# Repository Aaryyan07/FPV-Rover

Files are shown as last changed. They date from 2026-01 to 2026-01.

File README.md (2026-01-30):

# Arduino Mega Rover (Dual-Arm & FPV)

This is a custom-built rover project I designed using an Arduino Mega. It features a differential drive base, a robotic arm with 5 degrees of freedom, and a full FPV telemetry system.

The project is split into two main control systems: one for driving the wheels and one for operating the arm, both controlled simultaneously via two separate FlySky transmitters.

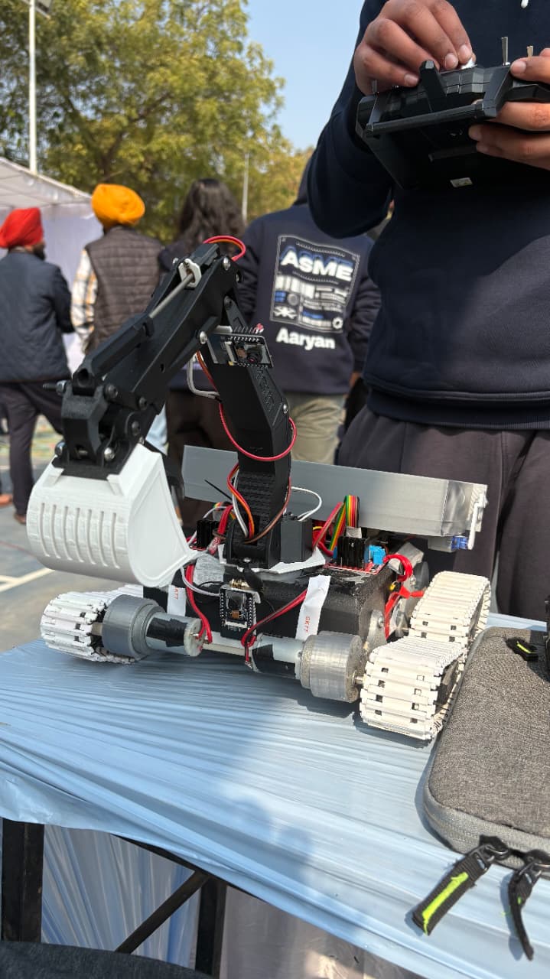
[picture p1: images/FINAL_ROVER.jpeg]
Final Rover Model


## Hardware Setup

### The Base (Drive System)
* **Motors:** 4x Johnson Geared Motors (12V DC, 500 RPM, Grade B).
* **Drivers:** 2x L298N Motor Drivers (controlling the 4 wheels).
* **Power:** Powered directly from the 12V rail of a PDB-XT60.

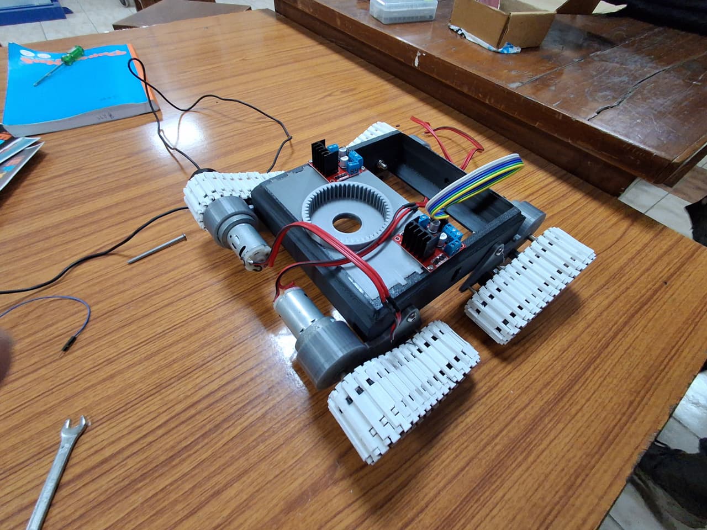
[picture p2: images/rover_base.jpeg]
Rover Base


### The Arm (Manipulation)
* **Actuators:** 5x N20 Motors with 100mm threaded shafts (Linear Actuators, 12V 1000 RPM).
* **Lift:** 1x N20 Motor.
* **Gripper:** Servo motor (PWM controlled via Arduino).
* **Drivers:** 3x TB6612FNG Dual Motor Drivers.
    * *Note: I used TB6612FNGs here instead of L298Ns to save space and reduce heat for the smaller arm motors.*
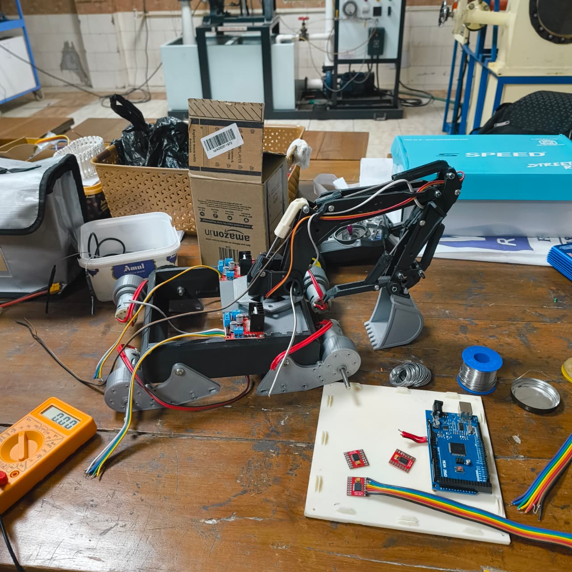
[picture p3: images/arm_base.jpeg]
Arm base


### Electronics & FPV
* **Microcontroller:** Arduino Mega (Handles all PWM logic and motor mixing).
* **RC Control:** 2x FS-IA10B Receivers paired with FlySky Transmitters.
* **Camera:** Foxeer Predator 5 connected to a Zeus HGLRC Nano VTX.
* **Video Receiver:** Skydroid 5.8GHz receiver with Lollipop antennas (RHCP) on both ends for better signal clarity.
* **Power:** 3S LiPo Battery (12.6V) connected to a PDB-XT60.

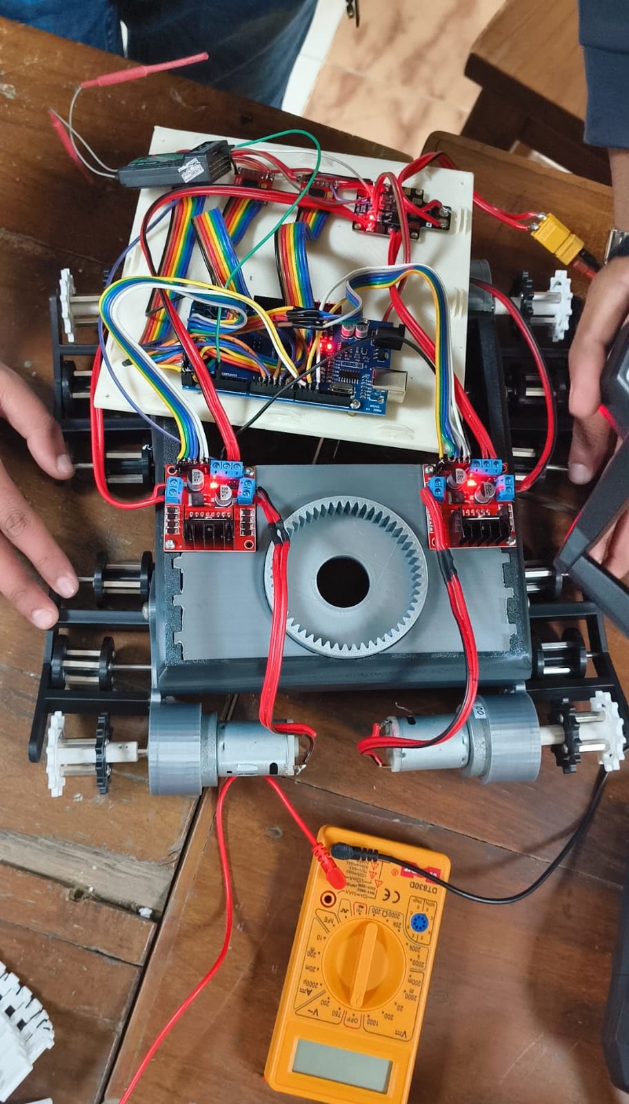
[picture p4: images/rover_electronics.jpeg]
Rover Electronics


## Wiring & Noise Reduction
One of the main challenges with this build was electrical noise from the DC motors interfering with the receiver signals.
* **Power Distribution:** The PDB-XT60 splits power: 12V to the drivers and 5V to the camera/transmitters.
* **Filtering:** I added capacitors across the motor driver terminals to smooth out voltage spikes and ensure the Arduino and receivers get a clean signal.

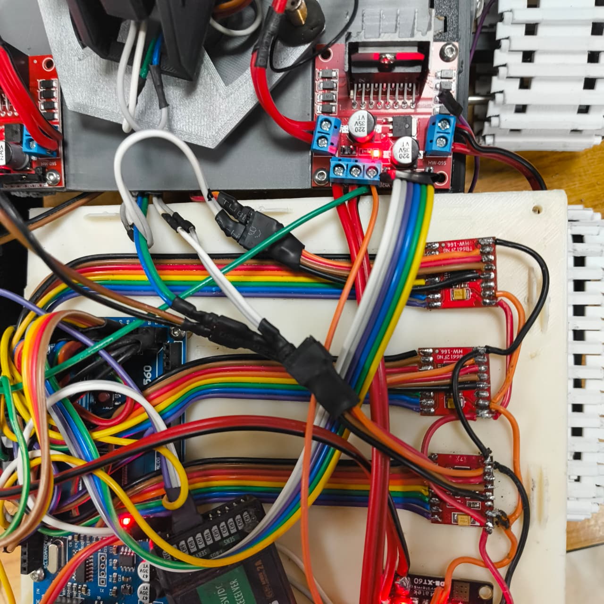
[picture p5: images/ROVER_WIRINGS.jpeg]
Wirings


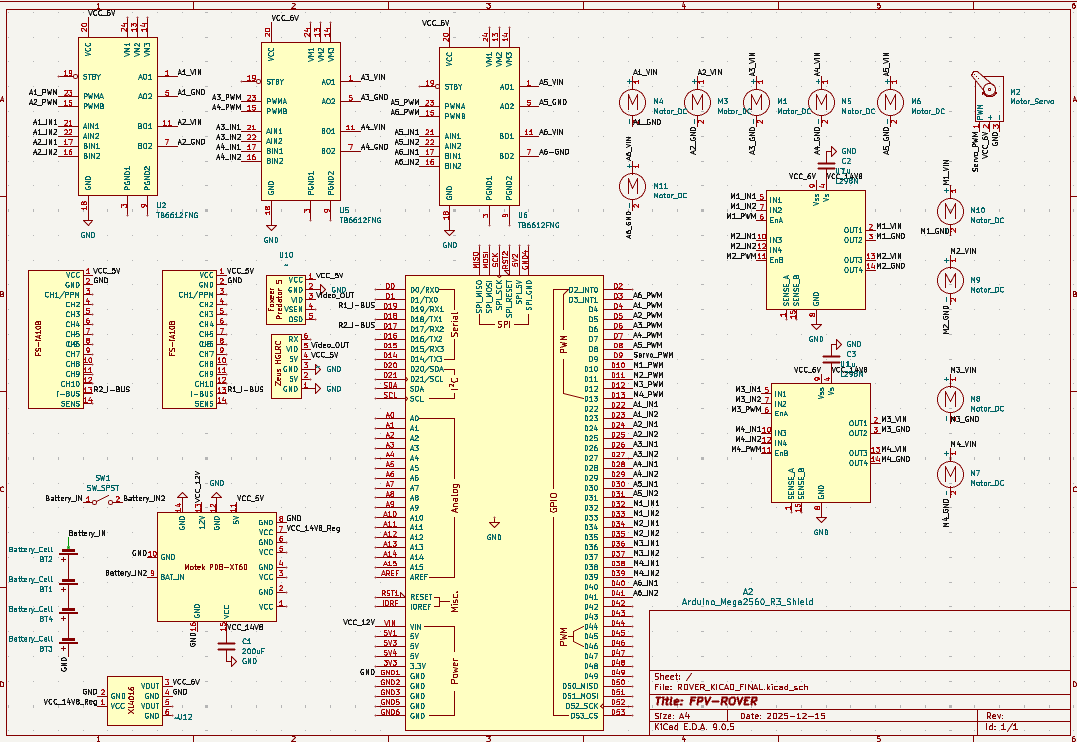
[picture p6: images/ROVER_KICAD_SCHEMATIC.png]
Schematic

## Fabrication
All mechanical parts (chassis, arm linkages, mounts) were 3D printed using **ABS filament** in the university mechanical lab. ABS was chosen over PLA for its higher heat resistance and durability.

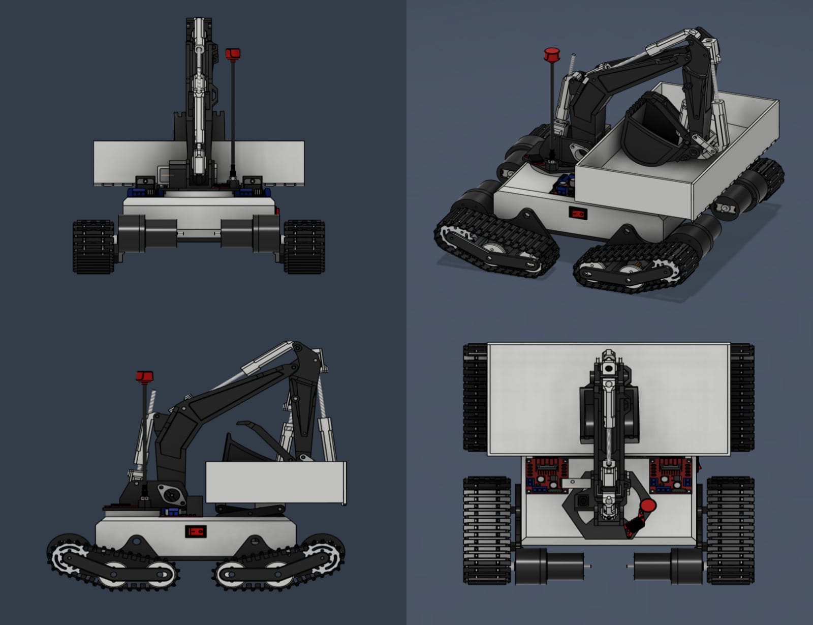
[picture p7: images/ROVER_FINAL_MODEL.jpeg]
Model


---
*Project by Aaryan Rathore*

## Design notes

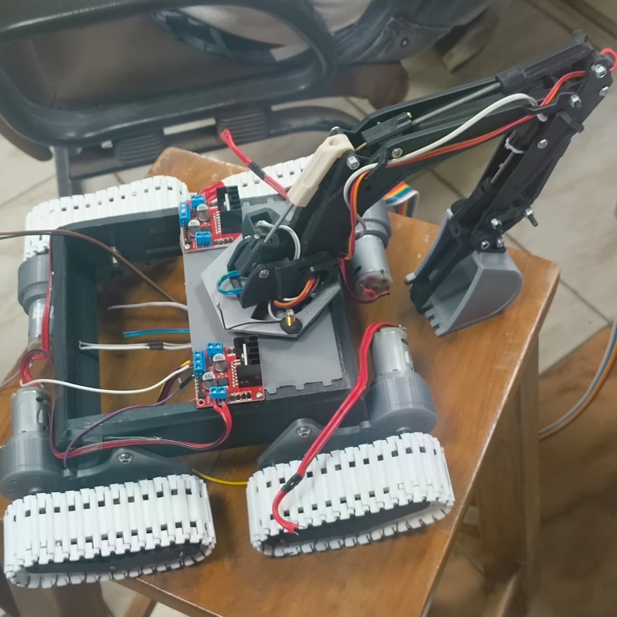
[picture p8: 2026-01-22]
images/rover_arm_base.jpeg

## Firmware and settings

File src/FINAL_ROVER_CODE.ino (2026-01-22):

#include <IBusBM.h>
#include <Servo.h>

const int MAX_SPEED_ROVER      = 255; 

const int MAX_SPEED_ARM_BASE   = 200;  
const int MAX_SPEED_ARM_LOWER  = 255;  
const int MAX_SPEED_ARM_UPPER  = 255;  
const int MAX_SPEED_ARM_DIGGER = 255;  
const int MAX_SPEED_ARM_CLIPPER= 200;  
const int MAX_SPEED_ARM_LIFT   = 255;  

const int SERVO_MIN_ANGLE      = 0;
const int SERVO_MAX_ANGLE      = 180;

const int LEFT_ENA = 2;   const int LEFT_IN1 = 49; const int LEFT_IN2 = 47; 
const int LEFT_IN3 = 45;  const int LEFT_IN4 = 43; const int LEFT_ENB = 3;

const int RIGHT_ENA = 10; const int RIGHT_IN1 = 37; const int RIGHT_IN2 = 35; 
const int RIGHT_IN3 = 33; const int RIGHT_IN4 = 31; const int RIGHT_ENB = 11;

const int SERVO_PIN = 9; 

const int D1_PWMA = 12;   const int D1_AIN1 = 46; const int D1_AIN2 = 44; 
const int D1_PWMB = 13;   const int D1_BIN1 = 48; const int D1_BIN2 = 50; 

const int D2_PWMA = 4;   const int D2_AIN1 = 28; const int D2_AIN2 = 26; 
const int D2_PWMB = 5;   const int D2_BIN1 = 30; const int D2_BIN2 = 32; 

const int D3_PWMA = 7;   const int D3_AIN1 = 38; const int D3_AIN2 = 36; 
const int D3_PWMB = 6;   const int D3_BIN1 = 40; const int D3_BIN2 = 42; 

const int STDBY1 = 22;
const int STDBY2 = 23;

const int CH_ROVER_ROLL = 0;    
const int CH_ROVER_PITCH = 1;   
const int CH_ROVER_SERVO = 4;   
const int CH_ROVER_LIFT = 3;    
const int CH_ROVER_EMERGENCY = 9;   

const int CH_ARM_LOWER = 0;     
const int CH_ARM_UPPER = 1;     
const int CH_ARM_SAFETY = 2;    
const int CH_ARM_BASE = 3;      
const int CH_ARM_DIGGER = 4;    
const int CH_ARM_CLIPPER = 5;   

const int CH_ARM_CALIBRATE = 7;    
const int CH_ARM_RESET_POS = 6;    

IBusBM IBusRover; 
IBusBM IBusArm;   
Servo myServo;    

int globalLeftSpeed = 0;
int globalRightSpeed = 0;

const int CALIBRATION_SPEED = 200; 

unsigned long lastDebugTime = 0;

unsigned long previousTime = 0;
float deltaTime = 0.0;

float posLeftA = 0.0, posLeftB = 0.0;
float posRightA = 0.0, posRightB = 0.0;
float posBase = 0.0, posDigger = 0.0, posClipper = 0.0;
float posLowerArm = 0.0, posUpperArm = 0.0, posLift = 0.0;

const float SPEED_TO_DIST = 0.5; 

const float CALIBRATION_TOLERANCE = 5.0;
const int SIGNAL_TIMEOUT = 1000; 
unsigned long lastValidSignalTime = 0;

void displayFullSystemDebug();
int mapSpeed(int rcVal, int maxLimit);

void setup() {
  Serial.begin(115200);
  previousTime = millis();
  
  pinMode(LEFT_ENA, OUTPUT);  pinMode(LEFT_IN1, OUTPUT);  pinMode(LEFT_IN2, OUTPUT);
  pinMode(LEFT_IN3, OUTPUT);  pinMode(LEFT_IN4, OUTPUT);  pinMode(LEFT_ENB, OUTPUT);
  pinMode(RIGHT_ENA, OUTPUT); pinMode(RIGHT_IN1, OUTPUT); pinMode(RIGHT_IN2, OUTPUT);
  pinMode(RIGHT_IN3, OUTPUT); pinMode(RIGHT_IN4, OUTPUT); pinMode(RIGHT_ENB, OUTPUT);

  pinMode(D1_PWMA, OUTPUT); pinMode(D1_AIN1, OUTPUT); pinMode(D1_AIN2, OUTPUT);
  pinMode(D1_PWMB, OUTPUT); pinMode(D1_BIN1, OUTPUT); pinMode(D1_BIN2, OUTPUT);
  pinMode(D2_PWMA, OUTPUT); pinMode(D2_AIN1, OUTPUT); pinMode(D2_AIN2, OUTPUT);
  pinMode(D2_PWMB, OUTPUT); pinMode(D2_BIN1, OUTPUT); pinMode(D2_BIN2, OUTPUT);
  pinMode(D3_PWMA, OUTPUT); pinMode(D3_AIN1, OUTPUT); pinMode(D3_AIN2, OUTPUT);
  pinMode(D3_PWMB, OUTPUT); pinMode(D3_BIN1, OUTPUT); pinMode(D3_BIN2, OUTPUT);

  pinMode(STDBY1, OUTPUT); digitalWrite(STDBY1, HIGH);
  pinMode(STDBY2, OUTPUT); digitalWrite(STDBY2, HIGH);

  myServo.attach(SERVO_PIN);
  
  IBusRover.begin(Serial1); 
  IBusArm.begin(Serial2);   

  Serial.println("SYSTEM READY. FULL DEBUG MODE + SPEED LIMITS ACTIVE.");
  lastValidSignalTime = millis();
}

void loop() {
  
  unsigned long currentTime = millis();
  deltaTime = (currentTime - previousTime) / 1000.0; 
  previousTime = currentTime;
  
  int emergencySignal = IBusRover.readChannel(CH_ROVER_EMERGENCY);
  int calibrateSignal = IBusArm.readChannel(CH_ARM_CALIBRATE);
  int resetPosSignal = IBusArm.readChannel(CH_ARM_RESET_POS);
  
  bool roverSignalValid = (IBusRover.readChannel(CH_ROVER_ROLL) >= 900 && IBusRover.readChannel(CH_ROVER_ROLL) <= 2100);
  bool armSignalValid = (IBusArm.readChannel(CH_ARM_LOWER) >= 900 && IBusArm.readChannel(CH_ARM_LOWER) <= 2100);
  
  if (roverSignalValid || armSignalValid) {
    lastValidSignalTime = millis();
  }
  
  if (emergencySignal > 1900 || (millis() - lastValidSignalTime > SIGNAL_TIMEOUT)) {
    setL298N(LEFT_ENA, LEFT_IN1, LEFT_IN2, 0);
    setL298N(LEFT_ENB, LEFT_IN3, LEFT_IN4, 0);
    setL298N(RIGHT_ENA, RIGHT_IN1, RIGHT_IN2, 0);
    setL298N(RIGHT_ENB, RIGHT_IN3, RIGHT_IN4, 0);
    
    moveArmMotor(D3_PWMA, D3_AIN1, D3_AIN2, 0);
    moveArmMotor(D1_PWMA, D1_AIN1, D1_AIN2, 0);
    moveArmMotor(D1_PWMB, D1_BIN1, D1_BIN2, 0);
    moveArmMotor(D2_PWMA, D2_AIN1, D2_AIN2, 0);
    moveArmMotor(D2_PWMB, D2_BIN1, D2_BIN2, 0);
    moveArmMotor(D3_PWMB, D3_BIN1, D3_BIN2, 0);
    
    if (millis() - lastDebugTime > 500) {
      if (emergencySignal > 1900) Serial.println("!!! EMERGENCY STOP ACTIVATED !!!");
      else Serial.println("!!! SIGNAL LOST - MOTORS STOPPED !!!");
      lastDebugTime = millis();
    }
    return; 
  }
  
  if (resetPosSignal > 1900) {
    posLeftA = 0.0; posLeftB = 0.0; posRightA = 0.0; posRightB = 0.0;
    posBase = 0.0; posDigger = 0.0; posClipper = 0.0;
    posLowerArm = 0.0; posUpperArm = 0.0; posLift = 0.0;
    
    if (millis() - lastDebugTime > 1000) {
       Serial.println("--- POSITIONS RESET TO 0.0 ---");
       lastDebugTime = millis();
    }
    return;
  }
  
  if (calibrateSignal > 1900) {
    myServo.write(SERVO_MIN_ANGLE); 
    setL298N(LEFT_ENA, LEFT_IN1, LEFT_IN2, 0);
    setL298N(LEFT_ENB, LEFT_IN3, LEFT_IN4, 0);
    setL298N(RIGHT_ENA, RIGHT_IN1, RIGHT_IN2, 0);
    setL298N(RIGHT_ENB, RIGHT_IN3, RIGHT_IN4, 0);

    int speedBase = calculateCalibrationSpeed(posBase);
    int speedDigger = calculateCalibrationSpeed(posDigger);
    int speedClipper = calculateCalibrationSpeed(posClipper);
    int speedLowerArm = calculateCalibrationSpeed(posLowerArm);
    int speedUpperArm = calculateCalibrationSpeed(posUpperArm);
    int speedLift = calculateCalibrationSpeed(posLift);

    moveArmMotor(D3_PWMA, D3_AIN1, D3_AIN2, speedBase);
    moveArmMotor(D1_PWMA, D1_AIN1, D1_AIN2, speedDigger);
    moveArmMotor(D1_PWMB, D1_BIN1, D1_BIN2, speedClipper);
    moveArmMotor(D2_PWMA, D2_AIN1, D2_AIN2, speedLowerArm);
    moveArmMotor(D2_PWMB, D2_BIN1, D2_BIN2, speedUpperArm);
    moveArmMotor(D3_PWMB, D3_BIN1, D3_BIN2, speedLift);

    updatePositions(0, 0, 0, 0, speedBase, speedDigger, speedClipper, speedLowerArm, speedUpperArm, speedLift);
    
    if (millis() - lastDebugTime > 250) { 
       displayFullSystemDebug();
       lastDebugTime = millis();
    }
    return;
  }

  int rawSafety = IBusArm.readChannel(CH_ARM_SAFETY); 
  int rawBase   = IBusArm.readChannel(CH_ARM_BASE);   
  
  int validBaseVal = 1500;
  if (rawSafety < 1100 && rawSafety > 800) { 
      validBaseVal = rawBase;
  }

  int rawLower   = IBusArm.readChannel(CH_ARM_LOWER);   
  int rawUpper   = IBusArm.readChannel(CH_ARM_UPPER);   
  int rawDigger  = IBusArm.readChannel(CH_ARM_DIGGER);  
  int rawClipper = IBusArm.readChannel(CH_ARM_CLIPPER); 

  int rawRoll   = IBusRover.readChannel(CH_ROVER_ROLL); 
  int rawPitch  = IBusRover.readChannel(CH_ROVER_PITCH);
  int rawServo  = IBusRover.readChannel(CH_ROVER_SERVO);
  int rawLift   = IBusRover.readChannel(CH_ROVER_LIFT); 

  if (millis() - lastDebugTime > 250) { 
    displayFullSystemDebug();
    lastDebugTime = millis();
  }

  if (rawServo >= 1000) {
      int sAngle = map(rawServo, 1000, 2000, SERVO_MIN_ANGLE, SERVO_MAX_ANGLE);
      myServo.write(sAngle);
  }
  
  int throttle = mapPulse(rawPitch);
  int steering = mapPulse(rawRoll);
  
  int leftMotorSpeed = throttle + steering;
  int rightMotorSpeed = throttle - steering;

  globalLeftSpeed = constrain(leftMotorSpeed, -MAX_SPEED_ROVER, MAX_SPEED_ROVER);
  globalRightSpeed = constrain(rightMotorSpeed, -MAX_SPEED_ROVER, MAX_SPEED_ROVER);

  setL298N(LEFT_ENA, LEFT_IN1, LEFT_IN2, globalLeftSpeed);
  setL298N(LEFT_ENB, LEFT_IN3, LEFT_IN4, globalLeftSpeed);
  setL298N(RIGHT_ENA, RIGHT_IN1, RIGHT_IN2, globalRightSpeed);
  setL298N(RIGHT_ENB, RIGHT_IN3, RIGHT_IN4, globalRightSpeed);

  int speedBase     = mapSpeed(validBaseVal, MAX_SPEED_ARM_BASE);
  int speedDigger   = mapSpeed(rawDigger, MAX_SPEED_ARM_DIGGER);
  int speedClipper  = mapSpeed(rawClipper, MAX_SPEED_ARM_CLIPPER);
  int speedLower    = mapSpeed(rawLower, MAX_SPEED_ARM_LOWER);
  int speedUpper    = mapSpeed(rawUpper, MAX_SPEED_ARM_UPPER);
  int speedLift     = mapSpeed(rawLift, MAX_SPEED_ARM_LIFT);

  moveArmMotor(D3_PWMA, D3_AIN1, D3_AIN2, speedBase); 
  moveArmMotor(D1_PWMA, D1_AIN1, D1_AIN2, speedDigger);    
  moveArmMotor(D1_PWMB, D1_BIN1, D1_BIN2, speedClipper);   
  moveArmMotor(D2_PWMA, D2_AIN1, D2_AIN2, speedLower);     
  moveArmMotor(D2_PWMB, D2_BIN1, D2_BIN2, speedUpper);     
  moveArmMotor(D3_PWMB, D3_BIN1, D3_BIN2, speedLift);      

  updatePositions(globalLeftSpeed, globalLeftSpeed, globalRightSpeed, globalRightSpeed,
                  speedBase, speedDigger, speedClipper, speedLower, speedUpper, speedLift);

  delay(10); 
}

void moveArmMotor(int pwm, int in1, int in2, int speed) {
  if (abs(speed) < 10) {
    digitalWrite(in1, LOW); digitalWrite(in2, LOW); analogWrite(pwm, 0);
  } else if (speed > 0) {
    digitalWrite(in1, HIGH); digitalWrite(in2, LOW); analogWrite(pwm, speed);
  } else {
    digitalWrite(in1, LOW); digitalWrite(in2, HIGH); analogWrite(pwm, abs(speed));
  }
}

int mapSpeed(int rcVal, int maxLimit) {
  if (rcVal < 800 || rcVal > 2200) return 0;
  
  int speed = map(rcVal, 1000, 2000, -maxLimit, maxLimit);
  
  if (abs(speed) < 35) speed = 0; 
  return speed;
}

int mapPulse(int val) {
  if (val < 900 || val > 2100) return 0;
  int out = map(val, 1000, 2000, -255, 255);
  return (abs(out) < 25) ? 0 : out;
}

void setL298N(int en, int in1, int in2, int speed) {
  if (abs(speed) < 20) {
    digitalWrite(in1, LOW); digitalWrite(in2, LOW); analogWrite(en, 0);
  } else if (speed > 0) {
    digitalWrite(in1, HIGH); digitalWrite(in2, LOW); analogWrite(en, speed);
  } else {
    digitalWrite(in1, LOW); digitalWrite(in2, HIGH); analogWrite(en, abs(speed));
  }
}

void updatePositions(int sLA, int sLB, int sRA, int sRB,
                     int sBase, int sDig, int sClip, int sLow, int sUp, int sLift) {
  posLeftA += sLA * deltaTime * SPEED_TO_DIST;
  posLeftB += sLB * deltaTime * SPEED_TO_DIST;
  posRightA += sRA * deltaTime * SPEED_TO_DIST;
  posRightB += sRB * deltaTime * SPEED_TO_DIST;
  posBase += sBase * deltaTime * SPEED_TO_DIST;
  posDigger += sDig * deltaTime * SPEED_TO_DIST;
  posClipper += sClip * deltaTime * SPEED_TO_DIST;
  posLowerArm += sLow * deltaTime * SPEED_TO_DIST;
  posUpperArm += sUp * deltaTime * SPEED_TO_DIST;
  posLift += sLift * deltaTime * SPEED_TO_DIST;
}

int calculateCalibrationSpeed(float currentPos) {
  if (abs(currentPos) < CALIBRATION_TOLERANCE) return 0;
  int direction = (currentPos > 0) ? -1 : 1;
  float distance = abs(currentPos);
  int speed = constrain((int)(distance * 2), 50, CALIBRATION_SPEED);
  return direction * speed;
}

void displayFullSystemDebug() {
  
  Serial.print("ROVER Rx [Ch1-10]: ");
  for(int i=0; i<10; i++) {
     Serial.print(IBusRover.readChannel(i));
     Serial.print("  ");
  }
  Serial.println(); 

  Serial.print("ARM   Rx [Ch1-10]: ");
  for(int i=0; i<10; i++) {
     Serial.print(IBusArm.readChannel(i));
     Serial.print("  ");
  }
  Serial.println(); 

  Serial.print("POS | Base:"); Serial.print(posBase, 1);
  Serial.print(" Low:"); Serial.print(posLowerArm, 1);
  Serial.print(" Up:"); Serial.print(posUpperArm, 1);
  Serial.print(" Dig:"); Serial.print(posDigger, 1);
  Serial.print(" Clip:"); Serial.print(posClipper, 1);
  Serial.print(" Lift:"); Serial.print(posLift, 1);
  
  Serial.println("\n-------------------------------------------------------------");
}

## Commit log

2026-01-22 Add README for Arduino Mega Rover project
    Added detailed project description, hardware setup, wiring, and fabrication notes for the Arduino Mega Rover.
2026-01-30 Update schematic image format in README
